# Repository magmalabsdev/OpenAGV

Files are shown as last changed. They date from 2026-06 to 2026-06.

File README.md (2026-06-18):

zine

# OpenAGV

A fully autonomous railcar for item transportation. When called remotely via wifi, the railcar autonomously navigates along a set of tracks using preplaced NFC tags to navigate to its destination. 
The car can be called from WiFi in an app. Doors should automatically open when it arrives 
at its destination. From there, load or unload your items, complete the task in the app, and the railcar will navigate to its next destination. 

Onshape (cad)

https://cad.onshape.com/documents/e8be59947376d7d19e89c19e/w/32dc181e05829722aa1fd0af/e/f831f93934d4714405e4e068

## Drivetrain

Screenshot 2026-06-13 at 5 10 01 PM

Uses dual 100KV 3536 motors with a 3:1 reduction to independently control left and right wheels.
Wheels are 85mm in diameter and 26mm thick
Includes two servo pointers for steering on top of asymmetric drive
Uses a PN532 NFC reader to confirm its position along tracks and intersections

## Electrical

Screenshot 2026-06-13 at 4 59 33 PM

The electrical bay in the back of the railcar hold the primary electrical components including the Echo control board and all three batteries. The primary two batteries are independently wired to their respective motors while the third smaller battery is used to power onboard components.
Wires are routed through channels in the windshield, cargo bay, and door to their destinations. 

The control board is a 3DBuffalo Echo powered by an ESP32-S3. This board controls the drive motors through ESC, steering servos, door motors, navigation NFC reader and eight LiDAR sensors through a shared I2C bus, SD card slot, speaker, and three onboard LED matrices. 
One 64x8 LED matrix is placed inside of the railcar on the electrical bay.

This railcar supports UART communication, up to four bay servos, and up to three bay DC motors through pogo pins in the cargo bay for custom loading, unloading, and processing mechanisms.

## Windshield

Screenshot 2026-06-13 at 5 07 01 PM

Each railcar has two windshields, one at each end. Each windshield includes four VL53L1X Lidar sensors for collision avoidance and an LED matrix to display relevant information. 
The top 28mm and bottom 32mm of each windshield consists of channels for running wires from other components into the electrical bay and to hold the sliding door. 
The majority of the remaining space in the windshield is taken up by a 3mm thick window.

## Cargo Bay & Door

Screenshot 2026-06-13 at 5 22 42 PM

The cargo bay has a storage volume of 336mm x 168mm x 180mm, all of which is directly accessible when the door is opened. The gridfinity baseplate along with pogo pins on the base allow for endless custom bay configurations for different use cases. 
The door uses a 7-panel hinged design driven by a N20 motor to rotate out of the way while requiring zero external clearance. A magnetic latch at the end of the door keeps it locked during standard operation. 
Door panels and the bay roof are entirely transparent allowing users to view the cargo from nearly all angles. 

## Tech Specs

<br>

|  |  |
| --- | --- |
| Cargo volume | 336mm x 168mm x 180mm |
| Railcar size | --- x 384mm x --- |
| Cargo bay interface  | Gridfinity |
| UI | Dual 32x8 LED dot display + 64x8 LED dot display |
| Supported auxillary servos | 4 |
| Lidar sensors | 8 |
| Battery size | 195.36 Wh |
| Motors | Dual A3536 100KV |
| Reduction | 3:1 |
| Control board | 3DBuffalo Echo |

# How to build

## Tools required
You will need access to an FDM 3d printer, and ideally an SLA 3d printer for transparent parts, though the car will function without transparent parts. 
Also needed are 
- Screwdriver
- Soldering iron and soldering materials
- Glue (for magnets)

## Building the drivetrain

### Parts needed
- Produce the following parts
  - 2X Side structural plate
  - 2X Motor Structural Plate
  - 1X Bottom Structural Plate
  - 1X Railcar Back Panel (in elec bay)
  - 4X 5mm OD 55mm L Steel Shaft
  - 4X 8mm OD 5mm ID 10mm L Spacer
  - 2X Servo horn to hinge coupler
  - 2X Rail Navigation Pointer
  - 2X Custom Servo Horn
  - 2X 3mm OD 10mm L Steel Shaft

- Prepare the following parts
  - 2X Brushless Motor D3536 100KV
  - 4X 2GT Timing Pulley Bore 2mm 60T
  - 2X 2GT Timing Pulley Bore 2mm 20T Double sided
  - 4X 85m Solid Large Load Bearing Rubber Tyre
  - 2X 2mm Pitch GT2 Timing Belt 108 Tooth
  - 2X MG995 55G (or similar) Servo Motor
  - 6X F624ZZ Ball Bearings
  - 2X PN532 NFC Reader
 
  - 4X M4x4 Socket Screw
  - 41X M4x8 Countersunk Screw
  - 4X M4x8 Socket Screw
  - 8X M3 Nut
  - 8X M3x6 Countersunk Screw
  - 8X M3x12 Socket Screw
  - 2X M2.5 Large Washer
  - 2X M2.5 X 6 Socket Screw
  - 8X M3x10 Socket Screw
  - 2X M3x6 Button Screw
  - 18X M3 Threaded Insert
  - 49X M4 Threaded Insert

### Assembling the motor plates

- Install 14 M4 threaded inserts on the edge holes of the motor plate
- Attach motor to motor plate using the included mounting bracket and four M3 nuts
- Push bearings into place on motor plate with the flange on the opposite side of the motor
- Attach dual 20T pulley to motor shaft using its coupler through the center bearing
- Install two steel shafts through the remaining bearings
- Install wheels on the motor side of the plate using their couplers
- Position the plate with the motor and wheels on the left side
- Install one 60T Pulley with its belt on the lower wheel
    - the coupler should facing right
- Place a 10mm spacer ton the other wheel shaft
- Install the other pulley with the coupler touching the spacer
- Install its matching belt
- Repeat for both motor plates, mirroring your steps the other one

### Assembling the drivetrain

- Ensure you have wires coming out of the servo motors and PN532 NFC readersm at least 100mm long
- Assemble two motor plates using the instructions above
- Install 16 M4 threaded inserts in the sides and on the servo mounting blocks of the bottom structural plate
- Install 2 M3 threaded inserts in the two PCB mounting standoffs on the bottom structural plate
- Install the PN532 using its two mounting holes and two M3x6 Button screws

- Assemble two servo motors using four M4x8 socket screws
- Place the railcar with the servo shafts facing up
- Install 4 M3 threaded inserts into each custom servo horn
- Assemble and screw down the custom servo horns using the M2.5 screws and washers
- Couple the servo horn to hinge couplers to the servo horn using four M3x10 socket screws each
- Install a 3mm OD 10mm L shaft to connect a coupler to a navigation pointer
- Lock the shaft into place using two M4x4
- Repeat for both servos

- Install four M4 threaded inserts into the holes of the side structural plates
- Install eight M4 threaded inserts into the mounting holes of the railcar back panel
- Attach the bottom structural plate to one motor plate using M4x8 Countersunk screws
  - It should be obvious where this plate goes, it is the one with the bent bottom
- Attach two side structural plates on either side of the motor/bottom plate using using M4x8 Countersunk screws
- Attach the railcar back panel using its mounting holes
- Pre-route your cables through the four cable channels on the back panel
- Install the other motor plate on the other side, sealing everything together

## Building the electrical bay

### Parts needed
- Produce the following parts
  - 1X Railcar Back Panel
  - 1X Elec Bay Bottom Channel
  - 1X Elec Bay Top Channel
  - 1X Echo Mounting Brace
  - 1X LED Matrix Mounting Brace
  - 1X I2C Multiplexer Mounting Brace
  - 2X Buck Converter Mounting Brace
  - 1X Elec-Cargo Bay Separation Panel
  - 5X Battery Clip
  - 2X Low Profile Battery Clip
  - 1X Secondary battery box
  - 14X 5mm OD 3.2mm ID 3mm H Custom Spacer
  - 8X 5mm OD 3.2mm ID 13mm H Custom Spacer
  - 10X 5mm OD 3.2mm ID 29mm H Custom Spacer

- Prepare the following parts
  - 1X 3DBuffalo Echo control board
  - 2X Zeee 4S 14.8V 3300mAh Lipo
  - 1X 650mAh 120C 3S Lipo
  - 2X 30A Brushless ESC
  - 1X XT30 to Bare Wire
  - 1X TCA9548A I2C 8-Channel Multiplexer
  - 2X LM2596 DC-DC Buck Converter Module
  - 1X MAX7219 Dot Matrix 8 in 1 Display Module
 
  - 10X M3x6 Button Screw
  - 18X M3x8 Button Screw
  - 4X M3x10 Button Screw
  - 8X M3x18 Button Screw
  - 3X M3x4 Countersunk Screw
  - 10X M3x35 Countersunk Screw
  - 45X M3 Threaded Insert

### Assembling the mounting hardware

- Install M3 threaded inserts in the mounting holes indicated on the diagram
(yellow dot = insert here)
Screenshot 2026-06-17 at 4 54 59 PM

- Tape down any wires you routed from the drivetrain temporarily
- Install M3 threaded inserts in the following positions on each mounting brace
  - Echo: The four corner holes on the ourside
  - Buck converter: The two holes on the ends
  - I2C Multiplexer: The two holes in the center
- Install 12 M3 threaded inserts in the mounting holes on the top and bottom electrical channels respectively
- Mount both channels to the back panel. The panel is symmetric so position does not matter for now
- Install the small battery box using three M3x4 countersunk screws
- Place the secondary battery into this box with wires facing outward
- Install the Echo mounting brace in the area between all four rectangular routing holes using M3x8 screws
  - There is only one position that fits

- Install two buck converter braces in the positions shown on the diagram with M3x8 screws
- Install the I2C Multiplexer brace in the position indicated in the diagram using M3x8 screws
- Install five battery clips using M3x6 screws as indicated in the diagram
- Install two low profile battery clips bordering the battery and LED matrix using M3x6 screws

### Assembling the electronics

- Install the Echo using M3x8 screws through 3mm spacers to its mounting brace, ensuring the GPIO is on the I2C Multiplexer side
- Install the buck converters onto their mounting braces ensuring IN faces the battery (for the echo) and the OUT faces the near end of the LED matrix (for the led matrix)
- Install the I2C Multiplexer onto its mounting brace using M3x8 screws
- Install the LED matrix onto its mounting brace from behind, using the 13mm spacers and M3x18 screws
- Install the LED matrix mounting brace onto the board using M3x10 screws and placing 3mm spacers below the brace
- Place both batteries in the locations indicated by the diagram
  - Route battery wires through the holes in the low profile battery clips
- Use the remaining mounting holes to zip tie ESCs to the board
- Connect the ESC power wires to the motor and battery

### Routing the wires
- Route wires according to this wiring diagram

Screenshot 2026-06-13 at 4 59 33 PM

- When done routing wires
  - Place 10 29mm spacers on the edges of the board
  - Place the elec-cargo separation panel on top of these spacers
  - Screw down the panel using the M3x35 countersunk screws

## Building the windshields

### Parts needed
- Produce the following parts
  - 2X Unibody Windshield Frame
  - 2X Window
  - 14X Logo tile (6 spokes + 1 core)

- Prepare the following parts
  - 8X VL53L1X Lidar Sensor (4 per windshield)
  - 2X MAX7219 Dot Matrix 4 in 1 Display Module
 
  - 6X M3x5 Socket Screw
  - 8X M2x5 Socket Screw
  - 8X M3x5 Countersunk Screw

  - 18X M3 threaded insert

### Assembling the windshield

- Ensure you have wires running out of the LED matrices and Lidar sensors
- Install eight M4 threaded inserts in the sides of the windshield
- Install six M3 threaded inserts in the window mounting holes
- Paint or glue the seven colors of the logo as follows
  - Center: purple core
  - Top: Blue
  - Bottom: Green
  - Upper right: White
  - Lower right: yellow
  - Upper left: red
  - Lower left: orange
- Install the LED matrix using the M3x5 countersunk screws. 
- Install the window using the M3x5 socket screws
- Install four VL53L1X Lidar sensors using the M2 screws
- Route wires through the top and bottom channels of the windshield to the electrical bay
- Repeat for both windshields

## Building the door

### Parts needed
- Produce the following parts
  - 1X Door Bay Bottom Channel
  - 1X Door Bay Top Channel
  - 2X Door Bay Cap
  - 2X Upper Belt Clamp
  - 2X Lower Belt Clamp
  - 2X Door Endstop Magnetic Latch
  - 14X Custom Transparent Door Panel
  - 2X 3mm OD 30mm L Steel Shaft
  - 16X 2mm OD 150mm L Aluminum Shaft

- Prepare the following parts
  - 2X GA12-N20 (12V 500RPM) Gear Motor
  - 4X 20 Teeth 3mm Bore Timing Pulley
  - 2X 2mm Pitch GT2 Timing Belt 188 Tooth
  - 1X Set Screw Collars 3.05mm (10pcs)
  - 1X Flanged Ball Bearing 3mmx6mmx2.5mm (10pcs)
 
  - 4X M2x5 Socket Screw
  - 28X M3x10 Socket Screw
  - 4X M1.6x3 Socket Screw
  - 24X M3x5 Countersunk Screw
  - 4X M2 Nut
  - 6X 6x2 Round Magnet
  - 32X M3 Helicoil Insert
  - 24X M3 Heat Set Insert
  - 24X M4 Heat Set Insert

### Assembling the motion system

- Install M4 heat set inserts into the holes nearest the connecting bottom plate on the top and bottom chanels
- Install M3 heat set inserts into the countersunk holes on the top and bottom channels
- Push and lock four flanged bearings into the four larger holes in the center of the bottom channel, with the flange on the inside
- Install a 3mm shaft with a 20T pulley, shaft collar, and GT2 belt through both sets of bearings
- Clamp the shaft collar on the side of channel with wings
- Clamp the pulley with the collar facing towards the other shaft collar on the other side
- Using the M1.6 screws, install N20 motors onto the wings of the door bay bottom channel
- Couple a 20T 3mm pulley onto each motor shaft, connecting the other side of the belt
- Clamp the upper and lower belt clamps together on the belt, drilling small holes as needed and using the M2 screws

### Assembling the door panels

- Install helicoil inserts into the holes on the ends of door panels
- To attach two door panels together, thread a hole between their hinges and use M3x10 screws to lock them in place
- Repeat until you have 7 panels connected together
- Ensure one of your rods (the one on one end) is longer and extends below the door panels
- On the ends of the doors, attach magnetic endstop latches the same way
- Glue magnets in holes into the latches
- Assemble the door bay caps using the countersunk holes and M3x5 countersunk screws
- Glue the extended rod into the belt clamp's hole through the channel in the door bay caps

## Building the cargo bay

### Parts needed
- Completed assemblies required
  - Electrical bay
  - 2X windshield
  - Door 

- Produce the following parts
  - 1X Cargo Bay Bottom Panel
  - 1X Cargo Bay Base
  - 1X Cargo Bay Cover
  - 1X Front Cover Plate
  - 1X 8x4 Gridfinity Baseplate

- Prepare the following parts
  - 4X Pogo Pins Kit
 
  - 46X M4x10 Countersunk Screw
  - 24X M4x15 Socket Screw
  - 24X M3x8 Button Screw
  - 24X M3x5 Countersunk Screw
  - 104X 6x2 Round Magnet
  - 48X M3 Threaded Insert
  - 70X M4 Threaded Insert

### Assembly instructions

- Install M4 threaded inserts into the up-down facing spacers on the cargo bay base
- Install M3 threaded inserts into the small holes in the panel of the cargo bay base
- Mount both windshields to the electrical bay panel using M4x10 Countersunk Screws
- Mount pogo pin pads in holes on the cargo bay base using M1.6x8 screws and nuts
- Mount gridfinity baseplate onto cargo bay base using M3x8 button screws
- Route pogo pin wires through windshield channels to electrical bay
- Glue magnets in the remaining holes on the baseplate, ensuring the magnet's north pole faces up
- Mount the cargo bay base to the electrical bay channel using M4x15 Socket screws
- Similarly, mount the cargo bay cover window to the electrical bay channel
- Install the upper door channel with the cover plate preinstalled next to the cargo bay cover window using M4x15 screws
- Install the door assembly on the bottom using M4x15 screws, ensuring the screws on the door panels fit into the channels on the cover plates
- Cover the cargo bay base using the cargo bay cover and the M4x10 countersunk screws
- Finally, install the front cover plate using M4x10 Countersunk Screws

# Why I built this

Smart appliances exist everywhere now: washing machines, robot vacuum cleaners, and dishwashers all automate some component of a repetitive chore. But something these appliances don't have is integration. After one is done, you still have to manually transport items to the next appliance to begin its next operation. You still have to refill its supplies manually. 

OpenAGV bridges this gap. This railcar is designed to be able to move in any orientation and carry a large volume of items. It supports up to seven auxillary bay motors for the cases where the railcar alone can't fully automate a task. And the base is fully modular to allow for infinite configurations for unique, high complexity tasks.

Imagine your roomba runs out of cleaning fluid. After notifying a railcar, the car can drive to a specially designed shelf, pick up the required item, drive to the roomba's docking station, and refill it entirely automatically. 

Or say you're cooking dinner and forget a specific ingredient. Instead of taking your hands off the task at hand, you tell your smart speaker assistant to bring it to you. It sends a command to the railcar which navigates to the shelf, picks up the item, and brings it to you. 

OpenAGV can also be used within machines where destination count is high and traffic is low enough that building a conveyor belt would be impractical. 

These are just the surface of what a compact, wall mounted railcar like this enables. [zine.pdf](https://github.com/user-attachments/files/29071181/zine.pdf)
[zine.pdf](https://github.com/user-attachments/files/29071178/zine.pdf)

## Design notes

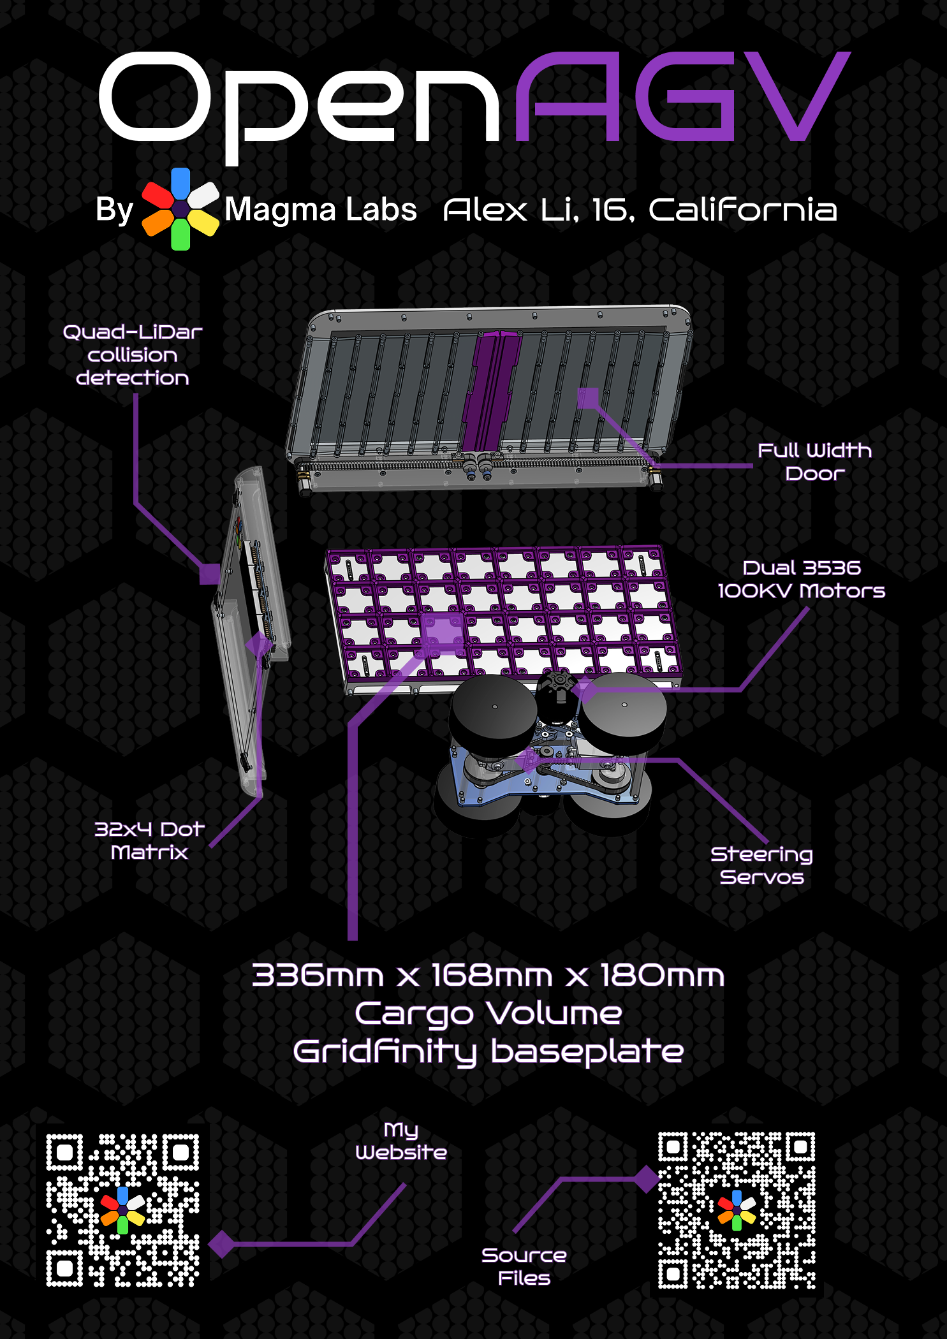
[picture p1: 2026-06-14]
media/zine.png

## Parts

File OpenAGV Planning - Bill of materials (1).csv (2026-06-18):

Item | Subassembly | Component | Order/Drawing | Unit price | Quantity | Total price | Status | Notes
Side structural plate (3DP) | Drivetrain | Structure |  |  | 2 |  | Need to manufacture | Print in PETG
Motor Structural Plate (3DP) | Drivetrain | Structure |  |  | 2 |  | Need to manufacture | Print in PETG
Bottom Structural Plate (3DP) | Drivetrain | Structure |  |  | 1 |  | Need to manufacture | Print in PETG
5mm OD 55mm L Steel Shaft | Drivetrain | Shaft |  |  | 4 |  | Need to manufacture | Cut to size
8mm OD 5mm ID 10mm L Spacer | Drivetrain | Structure |  |  | 4 |  | Need to manufacture | Print in PLA
Servo horn to hinge coupler | Drivetrain | Steering |  |  | 2 |  | Need to manufacture | Print in PA/PC
Rail Navigation Pointer | Drivetrain | Steering |  |  | 2 |  | Need to manufacture | Print in PA/POM
Custom Servo Horn | Drivetrain | Steering |  |  | 2 |  | Need to manufacture | Print in PA/PC
Brushless Motor D3536 100KV | Drivetrain | Drive | Ebay | 24.99 | 2 | 49.98 | Need to order
2GT Timing Pulley Bore 2mm 60T 4 pack | Drivetrain | Pulley | Amazon | 14.98 | 1 | 14.98 | Need to order
2GT Timing Pulley Bore 2mm 20T Double sided | Drivetrain | Pulley | Aliexpress | 6.48 | 2 | 12.96 | Need to order
2PCS 85m Solid Large Load Bearing Rubber Tyre | Drivetrain | Wheel | Amazon | 25.55 | 2 | 51.1 | Need to order
2mm Pitch GT2 Timing Belt 108 Tooth | Drivetrain | Belt | Servocity | 3.79 | 4 | 15.16 | Need to order
2Pcs MG995 55G Servo Motor | Drivetrain | Steering | Amazon | 13.98 | 1 | -- | Have it
6-Pack F624ZZ Ball Bearings | Drivetrain | Bearing | Amazon | 10.99 | 1 | 10.99 | Need to order
NFC Reader | Drivetrain | Navigation | Amazon | 8.99 | 1 | 8.99 | Need to order
Hex socket head cap screw M4x0.70 x 4 Stainless Steel | Drivetrain | Standard Parts |  |  | 4 |  | Unprocessed
Hex socket countersunk head screw M4x0.7 x 8 Stainless Steel | Drivetrain | Standard Parts |  |  | 41 |  | Unprocessed
Hex socket head cap screw M4x0.70 x 8 Stainless Steel | Drivetrain | Standard Parts |  |  | 4 |  | Unprocessed
Hex nut grade A & B M3x0.5 Stainless Steel | Drivetrain | Standard Parts |  |  | 8 |  | Unprocessed
Hex socket countersunk head screw M3x0.5 x 6 Stainless Steel | Drivetrain | Standard Parts |  |  | 8 |  | Unprocessed
Hex socket head cap screw M3x0.50 x 12 Stainless Steel | Drivetrain | Standard Parts |  |  | 8 |  | Unprocessed
Plain washer large grade A M2.5 Stainless Steel | Drivetrain | Standard Parts |  |  | 2 |  | Unprocessed
Hex socket head cap screw M2.5x0.45 x 6 Stainless Steel | Drivetrain | Standard Parts |  |  | 2 |  | Unprocessed | For attaching to servos
Hex socket head cap screw M3x0.50 x 10 Stainless Steel | Drivetrain | Standard Parts |  |  | 8 |  | Unprocessed | For coupling horn to hinge
Socket button head screw M3x0.5 x 6 Stainless Steel | Drivetrain | Standard Parts |  |  | 2 |  | Unprocessed | For NFC reader to bottom of drivetrain
M3 Threaded Insert | Drivetrain | Standard Parts |  |  | 18 |  | Unprocessed
M4 Threaded Insert | Drivetrain | Standard Parts |  |  | 49 |  | Unprocessed
Railcar Back Panel | Elec Bay | Structure |  |  | 1 |  | Need to manufacture | Print in PETG
Elec Bay Bottom Channel | Elec Bay | Structure |  |  | 1 |  | Need to manufacture | Print in PETG
Elec Bay Top Channel | Elec Bay | Structure |  |  | 1 |  | Need to manufacture | Print in PLA
Echo Mounting Brace | Elec Bay | Mounting |  |  | 1 |  | Need to manufacture | Print in PLA
5mm OD 3.2mm ID 3mm H Custom Spacer | Elec Bay | Mounting |  |  | 14 |  | Need to manufacture | Print in PLA
LED Matrix Mounting Brace | Elec Bay | Mounting |  |  | 1 |  | Need to manufacture | Print in PETG
5mm OD 3.2mm ID 13mm H Custom Spacer | Elec Bay | Mounting |  |  | 8 |  | Need to manufacture | Print in PLA
5mm OD 3.2mm ID 29mm H Custom Spacer | Elec Bay | Mounting |  |  | 10 |  | Need to manufacture | Print in PETG
Battery Clip | Elec Bay | Mounting |  |  | 5 |  | Need to manufacture | Print in PETG
Low Profile Battery Clip | Elec Bay | Mounting |  |  | 2 |  | Need to manufacture | Print in PETG
Buck Converter Mounting Brace | Elec Bay | Mounting |  |  | 2 |  | Need to manufacture | Print in PLA
I2C Multiplexer Mounting Brace | Elec Bay | Mounting |  |  | 1 |  | Need to manufacture | Print in PLA
Elec-Cargo Bay Separation Panel | Elec Bay | Structure |  |  | 1 |  | Need to manufacture | Print in PETG
3DBuffalo Echo | Elec Bay | Controller | 3DBuffalo | 54.99 | 1 | -- | Have it
2pcs Zeee 4S Lipo 14.8V 3300mAh | Elec Bay | Batteries | Aliexpress | 47.66 | 1 | 47.66 | Need to order
650mAh 120C Lipo Battery 3S | Elec Bay | Batteries | Aliexpress | 12.19 | 1 | 12.19 | Need to order
2-6S 70A 32-bit Bidirectional Brushless ESC with XT60 Connector | Elec Bay | ESC | Aliexpress | 21.81 | 2 | 43.62 | Need to order
XT30 to Bare Wire | Elec Bay | Wires | Gobilda | 2.49 | 1 | 2.49 | Need to order
TCA9548A I2C 8-Channel Multiplexer | Elec Bay | Communication | Amazon | 6.88 | 1 | 6.88 | Need to order
LM2596 DC-DC Buck Power Converter Module 2PCS | Elec Bay | Power Regulation | Amazon | 7.99 | 1 | 7.99 | Need to order
MAX7219 Dot Matrix 8 in 1 Display Module | Elec Bay | Information | Amazon | 13.99 | 1 | 13.99 | Need to order
Micro SD TF Card Adapter | Elec Bay | Data | Amazon | 5.99 | 0 | 0 | Cancelled
4 PCS Speaker 3 Watt 8 Ohm Mini Speaker | Elec Bay | Information | Amazon | 9.99 | 0 | 0 | Cancelled
Socket button head screw M3x0.5 x 8 Stainless Steel | Elec Bay | Standard Parts |  |  | 18 |  | Unprocessed
Socket button head screw M3x0.5 x 10 Stainless Steel | Elec Bay | Standard Parts |  |  | 4 |  | Unprocessed
Socket button head screw M3x0.5 x 18 Stainless Steel | Elec Bay | Standard Parts |  |  | 8 |  | Unprocessed
Socket button head screw M3x0.5 x 6 Stainless Steel | Elec Bay | Standard Parts |  |  | 10 |  | Unprocessed
Hex socket countersunk head screw M3x0.5 x 4 Stainless Steel | Elec Bay | Standard Parts |  |  | 3 |  | Unprocessed
Hex socket countersunk head screw M3x0.5 x 36 Stainless Steel | Elec Bay | Standard Parts |  |  | 10 |  | Unprocessed
M3 Threaded Insert | Elec Bay | Standard Parts |  |  | 45 |  | Unprocessed
Logo tiles (3DP) | Windshield | Branding |  |  | 6 + 1 |  | Need to manufacture | Print in matching color PLA
Unibody Windshield frame (3DP) | Windshield | Structure |  |  |  |  | Need to manufacture
Window (SLA3DP) | Windshield | Structure |  |  |  |  | Need to manufacture
VL53L1X lidar sensor 4pcs | Windshield | Detection | Amazon | 21.69 | 2 | 43.38 | Need to order
MAX7219 Dot Matrix 4 in 1 Display Module (2 pack) | Windshield | Information | Amazon | 12.99 | 1 | 12.99 | Need to order
Hex socket head cap screw M3x0.50 x 5 Stainless Steel | Windshield | Standard Parts |  |  | 6 |  | Have it
Hex socket head cap screw M2x0.40 x 5 Stainless Steel | Windshield | Standard Parts |  |  | 8 |  | Have it
Hex socket countersunk head screw M3x0.5 x 8 Stainless Steel | Windshield | Standard Parts |  |  | 8 |  | Have it
M2 Nuts | Windshield | Standard Parts |  |  | 8
M3 Nuts | Windshield | Standard Parts |  |  | 8
M3 Threaded Inserts | Windshield | Standard Parts |  |  | 6
Cargo Bay Bottom Panel (3DP) | Cargo Bay | Structure |  |  |  |  | Need to manufacture | Print in PETG
Cargo Bay Base (3DP) | Cargo Bay | Structure |  |  |  |  | Need to manufacture | Print in PETG
8x4 Gridfinity Baseplate (3DP) | Cargo Bay | Structure |  |  |  |  | Need to manufacture | Print in PLA
Cargo Bay Cover | Cargo Bay | Structure |  |  |  |  | Need to manufacture | Print in clear resin OR PETG depending on if you want a window
Front Cover Plate | Cargo Bay | Structure |  |  |  |  | Need to manufacture | Print in PETG
Pogo pins kit | Cargo Bay | Power | Amazon | 7.99 | 4 | 31.96 | Need to order
Hex socket countersunk head screw M4x0.7 x 10 Stainless Steel | Cargo Bay | Standard Parts |  |  | 46 |  | Unprocessed
Hex socket head cap screw M4x0.70 x 15 Stainless Steel | Cargo Bay | Standard Parts |  |  | 24 |  | Unprocessed
Socket button head screw M3x0.5 x 8 Stainless Steel | Cargo Bay | Standard Parts |  |  | 24 |  | Unprocessed
Hex socket countersunk head screw M3x0.5 x 5 Stainless Steel | Cargo Bay | Standard Parts |  |  | 24 |  | Unprocessed
6x2 Round Magnet | Cargo Bay | Standard Parts |  |  | 104 |  | Unprocessed
M3 Threaded Inserts | Cargo Bay | Standard Parts |  |  | 48 |  | Unprocessed
M4 Threaded Inserts | Cargo Bay | Standard Parts |  |  | 70 |  | Unprocessed
Door Bay Bottom Channe (3DP) | Door | Structure |  |  | 1 |  | Need to manufacture | Print in PETG
Door Bay Top Channel (3DP) | Door | Structure |  |  | 1 |  | Need to manufacture | Print in PLA
Door Bay Cap (3DP) | Door | Motion |  |  | 2 |  | Need to manufacture | Print in PETG
Upper Belt clamp (2PCS 3DP) | Door | Motion |  |  | 2 |  | Need to manufacture | Print in PETG
Lower Belt clamp (2PCS 3DP) | Door | Motion |  |  | 2 |  | Need to manufacture | Print in PETG
SLA3DP Custom Transparent Door Panel | Door | Structure |  |  | 14 |  | Need to manufacture | Print in clear resin
3DP Door Endstop Magnetic Latch | Door | Structure |  |  | 2 |  | Need to manufacture | Print in PLA
3mm OD 30mm L Steel Shaft (2PCS Cut to length) | Door | Structure |  |  | 2 |  | Need to manufacture | Cut to length
2mm OD 150mm L Aluminum Shaft (Cut to length) | Door | Structure |  |  | 16 |  | Need to manufacture | Cut to length
10pcs Set Screw Collars 3.05mm | Door | Belt clamp | Amazon | 6.79 | 1 | 6.79 | Need to order
20 Teeth 3mm Bore Timing Pulley 2 pack | Door | Pulley | Amazon | 6.69 | 2 | 13.38 | Need to order
Flanged Ball Bearing 3mmx6mmx2.5mm 10pcs | Door | Bearing | Amazon | 11.89 | 1 | 11.89 | Need to order
2mm Pitch GT2 Timing Belt 188 Tooth | Door | Belt | Servocity | 6.59 | 2 | 13.18 | Need to order
2pcs GA12-N20 N20 (12V 500RPM) Gear Reducer Motor | Door | Motor | Amazon | 9.99 | 2 | 19.98 | Need to order
Hex socket head cap screw M2x0.40 x 5 Stainless Steel | Door | Standard Parts |  |  | 4 |  | Unprocessed
Hex nut grade A & B M2x0.4 Stainless Steel | Door | Standard Parts |  |  | 4 |  | Unprocessed
Hex socket head cap screw M3x0.50 x 10 Stainless Steel | Door | Standard Parts |  |  | 28 |  | Unprocessed
Hex socket head cap screw M1.6x0.35 x 3 Stainless Steel | Door | Standard Parts |  |  | 4 |  | Unprocessed
Hex socket countersunk head screw M3x0.5 x 5 Stainless Steel | Door | Standard Parts |  |  | 12 |  | Unprocessed
6x2 Round Magnet | Door | Standard Parts |  |  | 6 |  | Unprocessed
M3 Helicoil Inserts: 32 | Door | Standard Parts |  |  | 32 |  | Unprocessed
M3 Heat Set Inserts: 12 | Door | Standard Parts |  |  | 12 |  | Unprocessed
Wheel interface pad | Rails | Structure |  |  | 2 Per 200mm |  | Need to manufacture | Print in TPU or use panels
Rail Bracket | Rails | Structure |  |  | 1 Per 200mm |  | Need to manufacture | Print in PA/PC
Peg Contact Rail | Rails | Structure |  |  | 1 Per 800mm |  | Need to order | Bent metal is best but high strength plastic works
NFC Tags | Rails | Navigation | Amazon | 12.34 | 4 per intersection, 1 per station |  | Need to order
Rail Intersection | Rails | Intersection |  |  |  |  | Need to order | No good known way to manufacture atm, DFM in progress
Hex socket countersunk head screw M3x0.5 x 12 Stainless Steel | Rails | Standard Parts |  |  | 6 per 200mm |  | Need to order
Loctite 243 Blue Medium Strength Threadlocker | Raw Material | Raw Material | Amazon | 15.81 | 1 | 15.81 | Need to order
5mm x 200mm 304 Stainless Steel Round Rod 5PCS | Raw Material | Raw Material | Amazon | 6.99 | 1 | 6.99 | Need to order
3mm x 150mm 304 Stainless Steel Round Rod 5PCS | Raw Material | Raw Material | Amazon | 5.99 | 1 | 5.99 | Need to order
2mm x 300mm 304 Stainless Steel Round Rod 5PCS | Raw Material | Raw Material | Amazon | 5.99 | 2 | 11.98 | Need to order
PLA Filament (Galaxy Purple) | Raw Material | Raw Material | Bambu Lab | 24.99 | 1 | -- | Have it
PETG Filament | Raw Material | Raw Material | Bambu Lab | 19.99 | 1 | 19.99 | Need to order
TPU Filament | Raw Material | Raw Material | Polymaker | 29.99 | 1 | -- | Have it
PA Filament | Raw Material | Raw Material | Polymaker | 49.99 | 1 | -- | Have it
TOTAL |  |  |  |  |  | 513.29
Too many screws? I got you covered | *note: this is summarized by AI: Cross check important info
M1.6
M1.6 x 3 | 4
M2
M2 X 3 | 8
M2 X 5 | 4
Hex nut M2×0.4 | 12
M2.5
M2.5 X 6 | 2
Plain washer large grade A M2.5 | 2
M3
Countersunk M3x4 | 3
Countersunk M3x5 | 44
Countersunk M3x6 | 8
Countersunk M3x12 | 12 + Rails
Countersunk M3x36 | 10
Socket M3x5 | 6
Socket M3x10 | 36
Socket M3x12 | 8
Button M3x6 | 12
Button M3x8 | 42
Button M3x10 | 4
Byttoin M3x18 | 8
Hex nut M3×0.5 | 16
Heat Set Inserts | 129
Helicoil Inserts | 12
M4
Countersunk M4x8 | 41
Countersunk M4x10 | 46
Socket M4x4 | 4
Socket M4x8 | 4
Socket M4x15 | 24
Heat Set Inserts | 119
https://www.amazon.com/QIYANGBRO-Momentary-Button-Assorted-Self-Resetting/dp/B0DP4BJSPJ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
https://www.amazon.com/4PcsThin-Pressure-Sensitivity-Industrial-Measurement/dp/B0FGD267GK
https://www.aliexpress.com/item/1005009383641508.html?src=google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

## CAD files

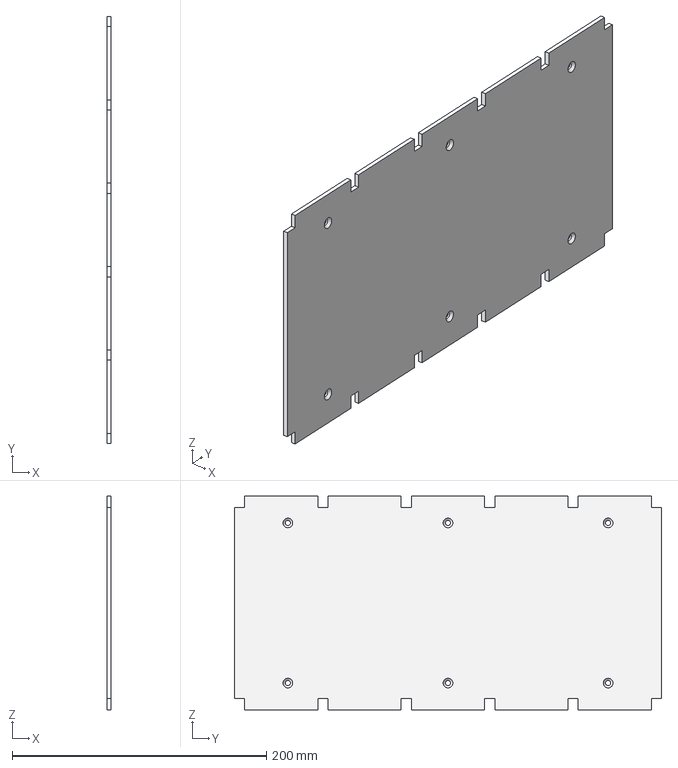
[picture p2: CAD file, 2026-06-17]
cad and bom/cargo bay/Body - Cargo Bay Bottom Panel.step
3.00 x 336.0 x 168.0 mm

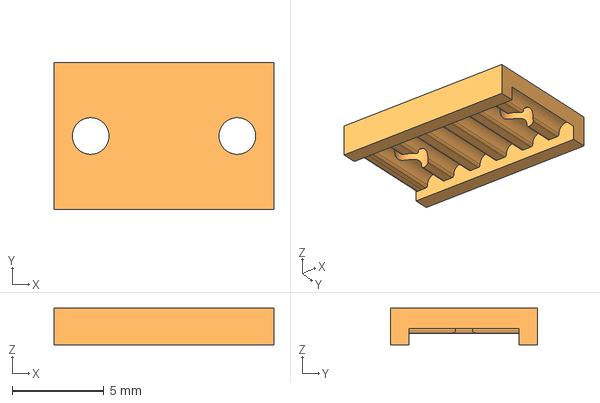
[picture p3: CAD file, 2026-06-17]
cad and bom/door/Lower Belt Clamp.step
12.0 x 8.00 x 2.00 mm

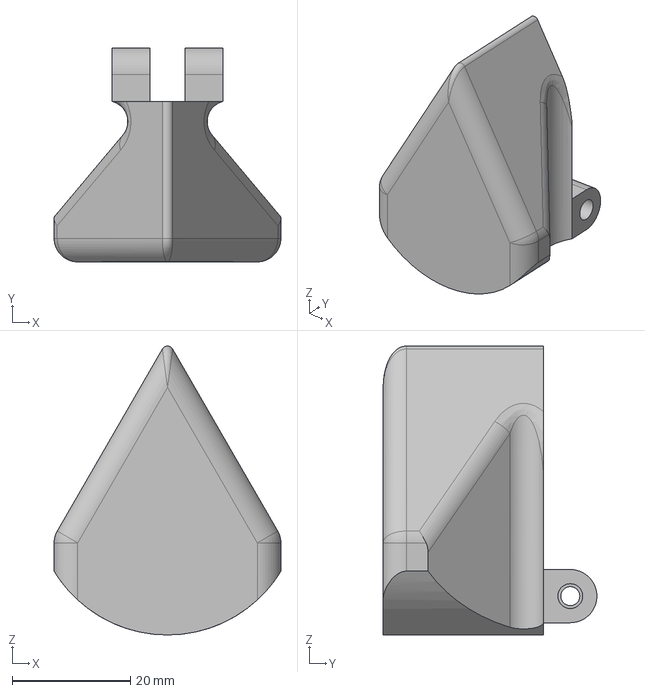
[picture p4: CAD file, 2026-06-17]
cad and bom/drivetrain/Rail Navigation Pointer.step
38.3 x 36.1 x 48.8 mm

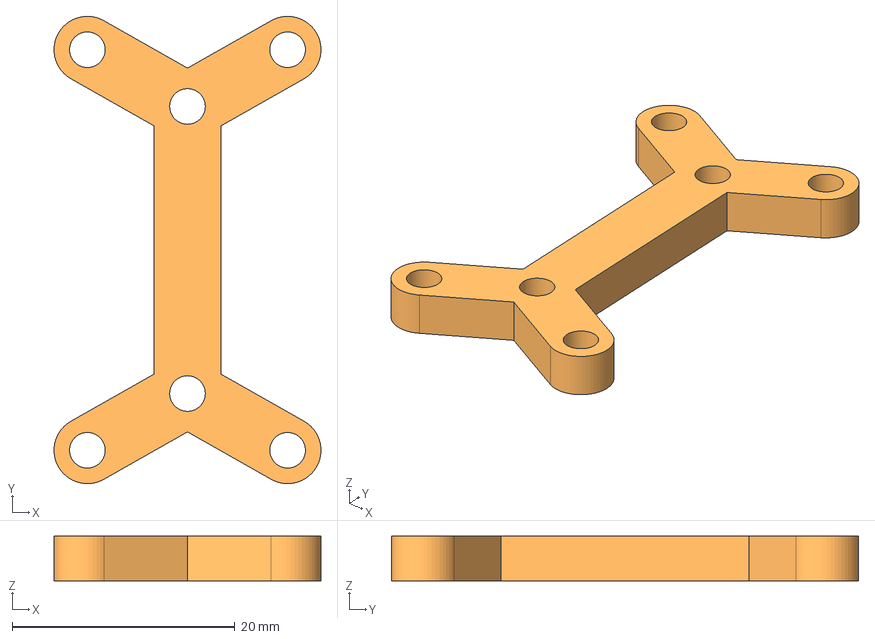
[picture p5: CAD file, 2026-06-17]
cad and bom/elec bay/Elec Bay Part Studio - I2C Multiplexer Brace.step
24.0 x 42.0 x 4.00 mm

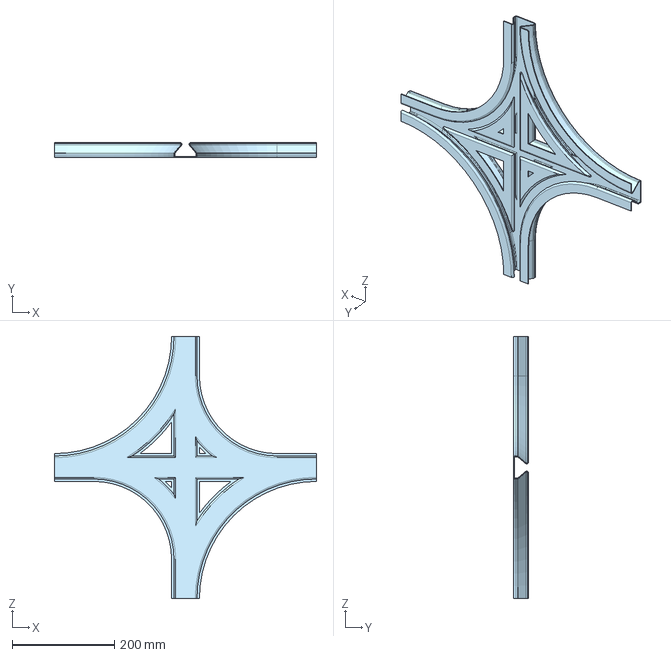
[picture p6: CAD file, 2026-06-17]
cad and bom/rails/Rail Intersection.step
512.0 x 28.7 x 512.0 mm

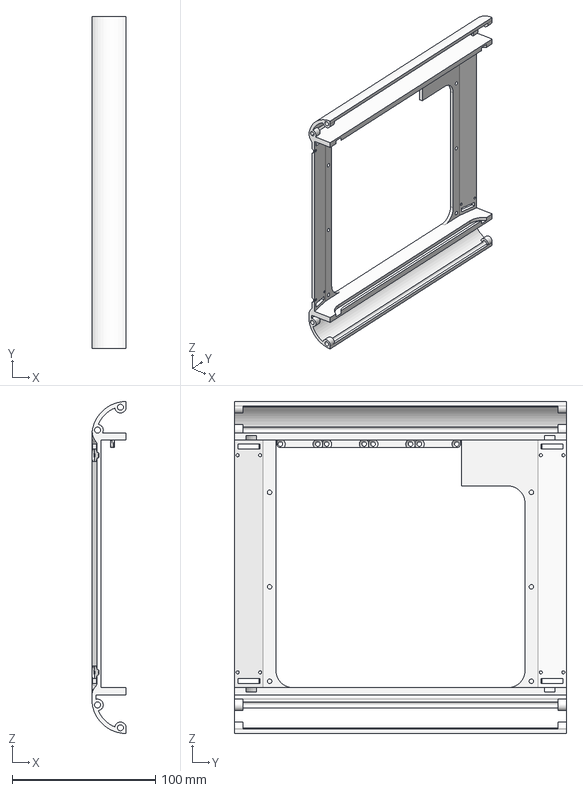
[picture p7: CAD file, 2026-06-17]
cad and bom/windshield/Windshield Part Studio - Unibody Windshield Frame.step
24.0 x 232.0 x 232.0 mm

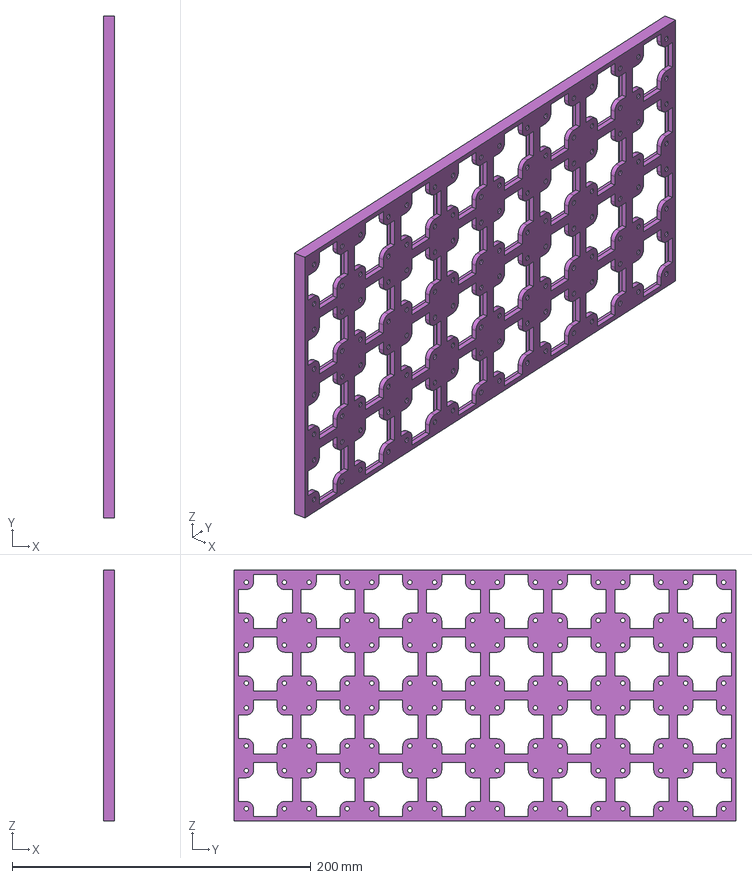
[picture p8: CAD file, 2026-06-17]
cad and bom/cargo bay/Body - Gridfinity Baseplate.step
7.55 x 336.0 x 168.0 mm

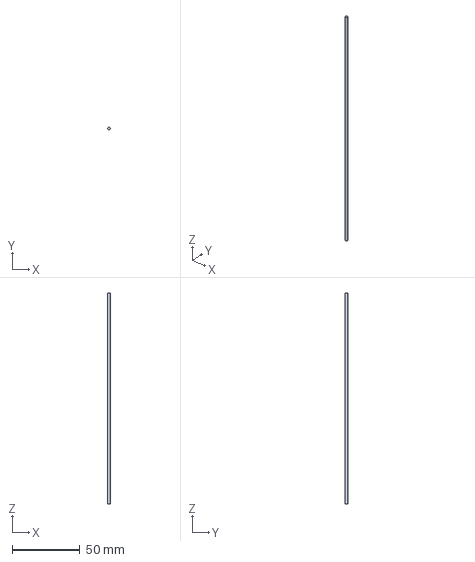
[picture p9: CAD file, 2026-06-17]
cad and bom/door/2mm OD 150mm L Aluminum Shaft (Cut to length).step
2.00 x 2.00 x 156.0 mm

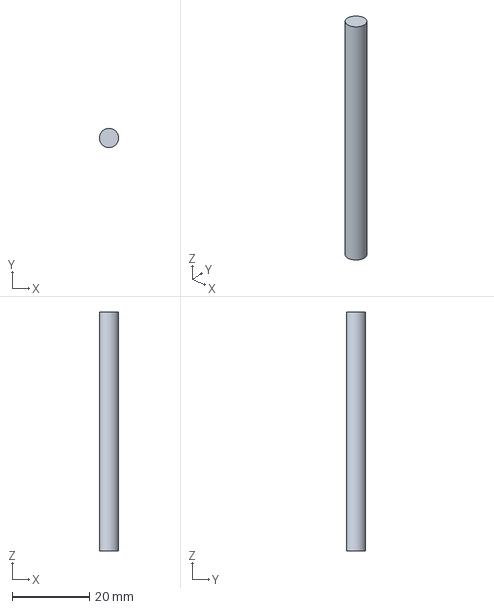
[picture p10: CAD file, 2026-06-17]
cad and bom/drivetrain/5mm OD 55mm L Steel Shaft.step
5.00 x 5.00 x 62.0 mm

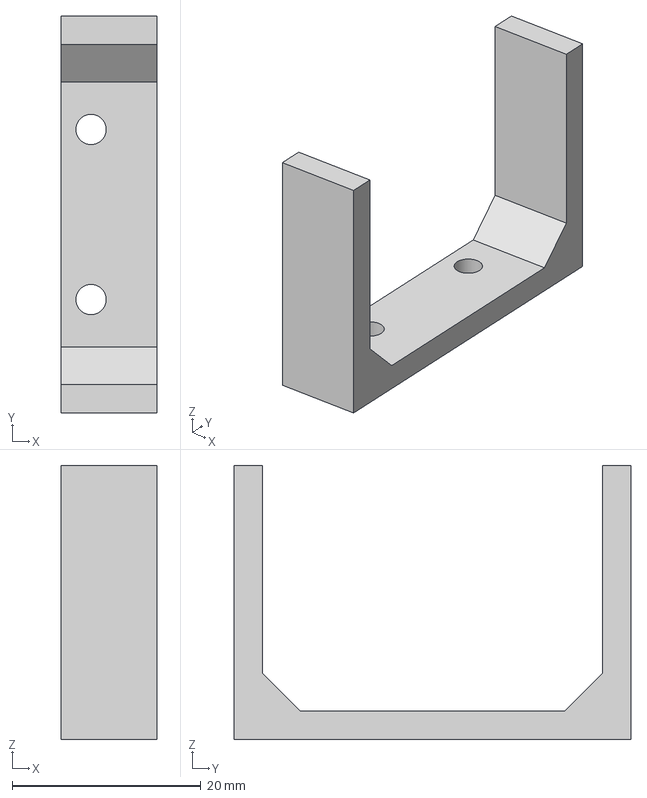
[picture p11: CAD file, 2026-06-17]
cad and bom/elec bay/Elec Bay Part Studio - Low Profile Battery Clip.step
10.2 x 42.0 x 29.0 mm

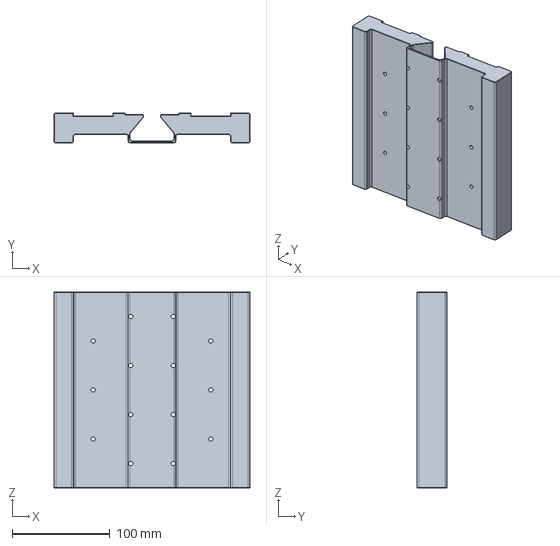
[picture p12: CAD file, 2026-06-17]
cad and bom/rails/Rail Profile - Rail Bracket.step
200.0 x 30.5 x 200.0 mm

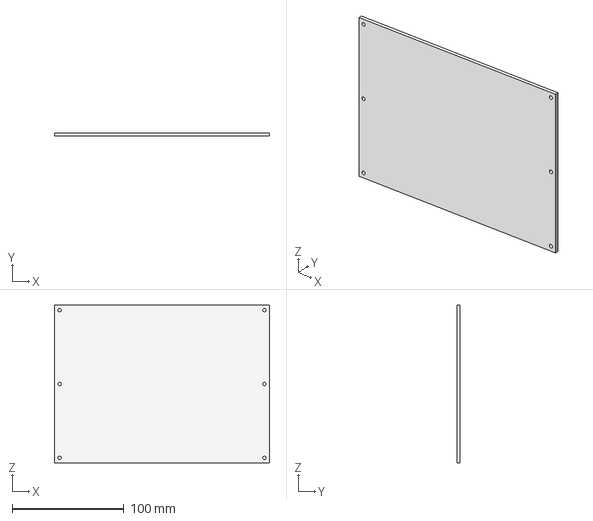
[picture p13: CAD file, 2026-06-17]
cad and bom/windshield/Windshield Part Studio - Window.step
192.0 x 3.00 x 141.0 mm

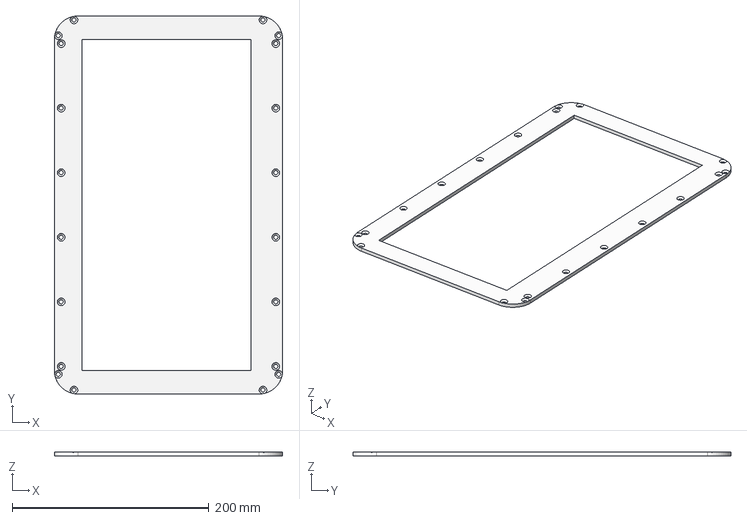
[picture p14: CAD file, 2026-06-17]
cad and bom/cargo bay/Body - Front cover plate.step
232.0 x 384.0 x 4.00 mm

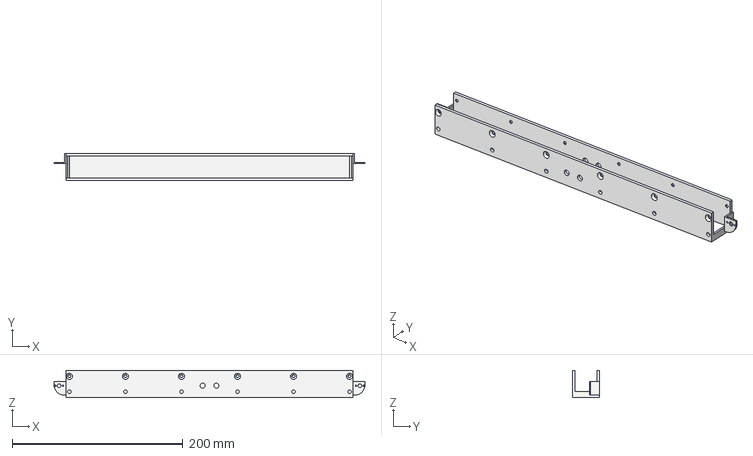
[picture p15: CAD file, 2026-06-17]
cad and bom/door/Door Part Studio - Door Bay Bottom Channel.step
364.2 x 32.0 x 32.0 mm

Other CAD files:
cad and bom/FullRailcar.step
cad and bom/drivetrain/Motor Part Studio - Motor Structural Plate.step
cad and bom/elec bay/Elec Bay - Bottom Channel.step
cad and bom/rails/Upper Belt Clamp.step
cad and bom/cargo bay/Body - Cargo Bay Base.step
cad and bom/cargo bay/Body - Cargo Bay Cover.step
cad and bom/door/3mm OD 30mm L Steel Shaft (2PCS Cut to length).step
cad and bom/door/Body - Door Bay Top Channel.step
cad and bom/door/Custom Transparent Door Panel.step
cad and bom/door/Door Part Studio - Door Bay Cap.step
cad and bom/door/Door Part Studio - Magnetic Latch.step
cad and bom/drivetrain/8mm OD 5mm ID 10mm L Spacer.step
cad and bom/drivetrain/Custom servo horn.step
cad and bom/drivetrain/Motor Part Studio - Bottom Structural Plate.step
cad and bom/drivetrain/Motor Part Studio - Side Structural Plate.step
cad and bom/drivetrain/Servo horn to hinge coupler.step
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

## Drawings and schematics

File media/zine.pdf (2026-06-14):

# OpenAGV

## Alex Li, 16, California

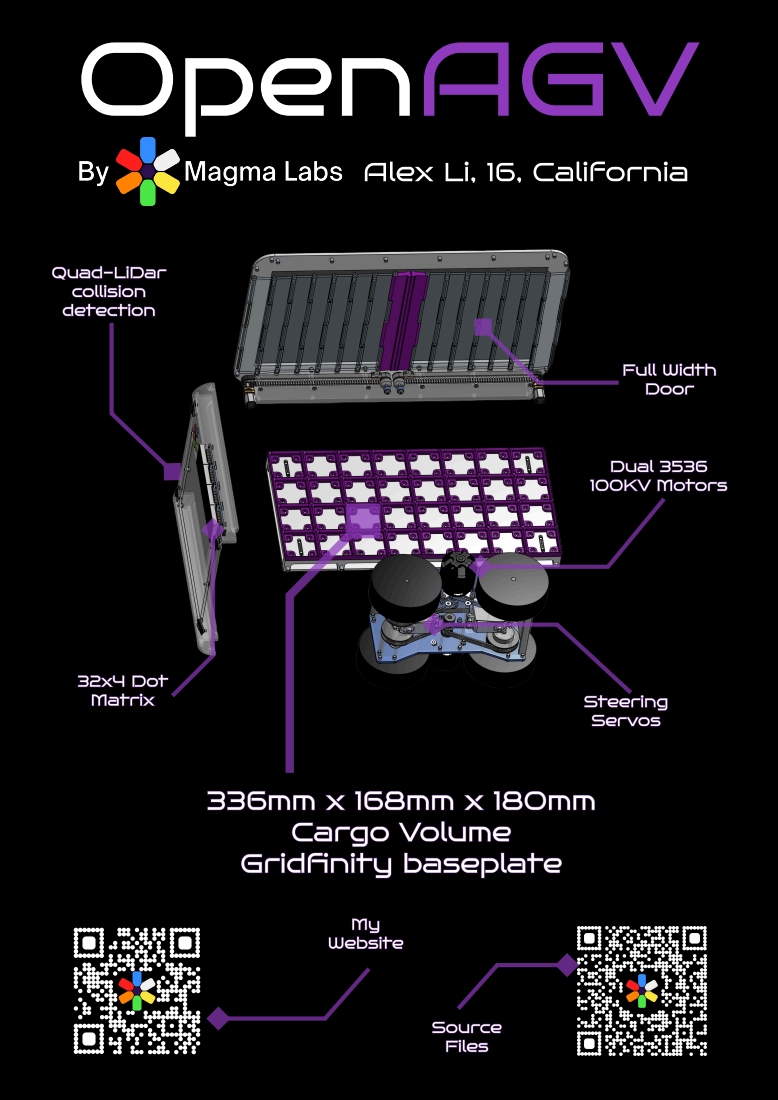
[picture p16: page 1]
Quad-LiDar collision detection; Full Width Door; Dual 3536 100KV Motors; 32x4 Dot; Matrix; Steering; Servos; 336mm x 168mm x 180mm Cargo Volume Gridfinity baseplate; My Website; Source Files

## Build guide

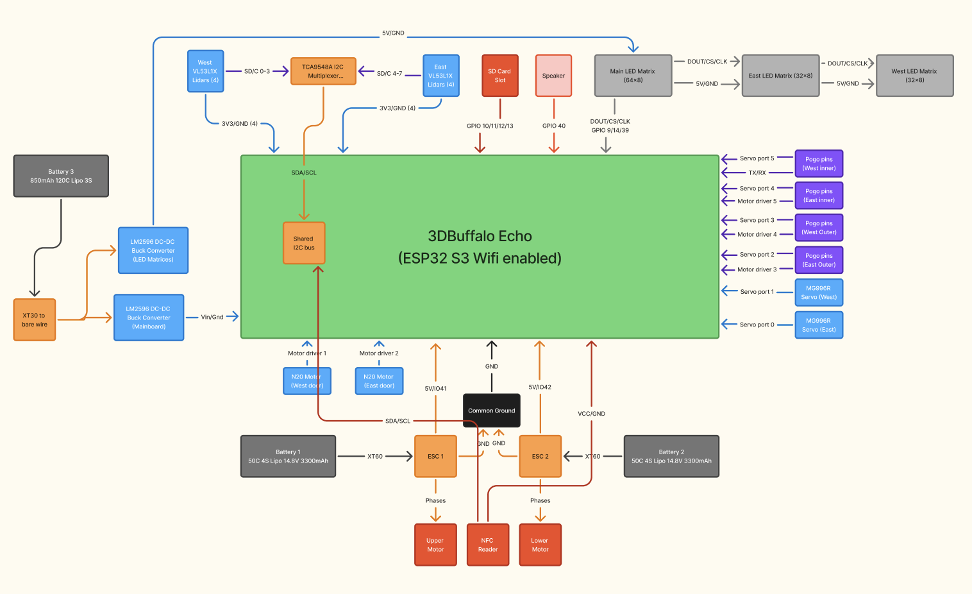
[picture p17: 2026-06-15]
wiring-diagram.png

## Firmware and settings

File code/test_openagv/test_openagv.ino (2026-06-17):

#include <EchoLib.h>
#include <LedControl.h>
#include <Servo.h>
#include <SPI.h>
#include <SD.h>
#include <string>
#include <Wire.h>
#include <array>

#define SPEAKER_PIN 40;

#define UPPER_MOTOR_PIN  41;
#define LOWER_MOTOR_PIN  42;

#define LEDMTX_DIN  9;
#define LEDMTX_CS  14;
#define LEDMTX_CLK  39;

#define WEST_DOOR_MOTOR  1;
#define EAST_DOOR_MOTOR  2;

#define MUX_ADDR 0x70;

MotorControllers mc =  MotorControllers();
LedControl lc = LedControl(DIN, CLK, CS,0);
ServoDriver sd;

Servo UPPER_ESC;
Servo LOWER_ESC;  

std::array<Adafruit_VL53L1X, 8> lidar {};

void setup() {



    Serial.begin(115200);
    
    while (!Serial) {
    delay(10);
    }
    Wire.begin();


    if (!SD.begin(10)) {
        Serial.println("initialization failed!");
        while (1);
    }

    File myFile = SD.open("test.txt");
    string text = myFile.read()
    Serial.write(text);
    myFile.close();

    UPPER_ESC.attach(UPPER_MOTOR_PIN,1000,2000);
    LOWER_ESC.attach(LOWER_MOTOR_PIN,1000,2000);

    servoDriver.init();
    
    lc.shutdown(0,false);
    lc.setIntensity(0,0);
    lc.clearDisplay(0);
    

}

void loop() {
    for(int j=0;j<8;j++){
         for(int i=0;i<8;i++){
            lc.setLed(0,j,i,true);
         }
    }

    UPPER_ESC.write(1023);




    for(int j=0;j<8;j++){
         for(int i=0;i<8;i++){
            lc.setLed(0,j,i,false);
         }
    }

    UPPER_ESC.write(0);
    delay(1000);

}


void tcaSelect(uint8_t bus) {
  if (bus > 7) return; // Only 8 channels available (0-7)
  
  Wire.beginTransmission(MUX_ADDR);
  Wire.write(1 << bus);          // Send a bitmask representing the active channel
  Wire.endTransmission();
}

void initializeLidar(){
    for(int i=0; i<8; i++){
        tcaSelect(i);
        Adafruit_VL53L1X vl53 = Adafruit_VL53L1X();
        lidar[i] = vl53;

        if (!vl53.begin(0x29 + i, &Wire)) {
            Serial.print("Error on init of VL sensor: ");
            Serial.println(vl53.vl_status);
            while (1) delay(10);
        }
        
        Serial.println("VL53L1X sensor found!");
        
        // Set distance range mode (1 = Short, 2 = Medium, 3 = Long)
        vl53.setDistanceMode(3);
        
        // Set timing budget (20ms, 33ms, or 100ms)
        vl53.setTimingBudget(100);

        // Start continuous ranging with 100ms inter-measurement period
        vl53.startRanging();

    }
    

}

void setMotorPower(float percentage){
    int toServoDegrees = (int) (percentage * 90 + 90)
    UPPER_ESC.write(toServoDegrees);
    LOWER_ESC.write(toServoDegrees);
}

std::array<int, 4> readWestLidar(){
    std::array<int, 4> westLidarChannels = {0, 1, 2, 3};
    std::array<int, 4> westLidarValues = {};

    for (int ch : westLidarChannels) {
        tcaSelect(ch);
        Adafruit_VL53L1X vl53 = lidar[ch]

        if (vl53.dataReady()) {
            int16_t distance = vl53.distance();
            
            if (distance == -1) {
            Serial.print("Couldn't get distance: ");
            Serial.println(vl53.vl_status);
            return;
            }
            westLidarValues[ch] = distance;
            
            vl53.clearInterrupt();
        }

    }       
    return westLidarValues;

}

std::array<int, 4> readEastLidar(){
    std::array<int, 4> eastLidarChannels = {4, 5, 6, 7};
    std::array<int, 4> eastLidarValues = {};

    for (int ch : eastLidarChannels) {
        tcaSelect(ch);
        Adafruit_VL53L1X vl53 = lidar[ch]

        if (vl53.dataReady()) {
            int16_t distance = vl53.distance();
            
            if (distance == -1) {
            Serial.print("Couldn't get distance: ");
            Serial.println(vl53.vl_status);
            return;
            }
            eastLidarValues[ch] = distance;
            
            vl53.clearInterrupt();
        }

    }       
    return eastLidarValues;
}

void openDoor(){
    motorControllers.set(WEST_DOOR_MOTOR, 100);
    motorControllers.set(EAST_DOOR_MOTOR, 100);
    delay(1000);
    motorControllers.set(WEST_DOOR_MOTOR, 0);
    motorControllers.set(EAST_DOOR_MOTOR, 0);
}

void closeDoor(){
    motorControllers.set(WEST_DOOR_MOTOR, -100);
    motorControllers.set(EAST_DOOR_MOTOR, -100);
    delay(1000);
    motorControllers.set(WEST_DOOR_MOTOR, 0);
    motorControllers.set(EAST_DOOR_MOTOR, 0);
}

void setLedMatrixText(const std::string &main, const std::string &east, const std::string &west){
    const int MAIN_MODULES = 8; // 64x8 (8 modules)
    const int EAST_MODULES = 4; // 32x8 (4 modules)
    const int WEST_MODULES = 4; // 32x8 (4 modules)
    const int MAIN_OFFSET = 0;
    const int EAST_OFFSET = MAIN_OFFSET + MAIN_MODULES;
    const int WEST_OFFSET = EAST_OFFSET + EAST_MODULES;

    auto writeToModules = [&](const std::string &s, int modules, int offset){
        for(int m = 0; m < modules; ++m){
            int dev = offset + m;
            lc.clearDisplay(dev);
            char ch = ' ';
            if(m < (int)s.length()) ch = s[m];
            // show a single character on this 8x8 module
            lc.setChar(dev, 0, ch, false);
        }
    };

    writeToModules(main, MAIN_MODULES, MAIN_OFFSET);
    writeToModules(east, EAST_MODULES, EAST_OFFSET);
    writeToModules(west, WEST_MODULES, WEST_OFFSET);
}

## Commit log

2026-06-15 Add bom
    [OpenAGV Planning - Bill of materials.csv]
2026-06-15 Updated Bom
    [OpenAGV Planning - Bill of materials.csv]
2026-06-15 we do a bit of organizing
    [OpenAGV Planning - Bill of materials.csv]
2026-06-15 wiring diagram forgot
2026-06-17 add cad files
    [2mm OD 150mm L Aluminum Shaft (Cut to length).step, 3mm OD 30mm L Steel Shaft (2PCS Cut to length).step, 5mm OD 3.2mm ID 13mm H Custom Spacer.step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]
2026-06-17 Add drivetrain assembly instructions to README
